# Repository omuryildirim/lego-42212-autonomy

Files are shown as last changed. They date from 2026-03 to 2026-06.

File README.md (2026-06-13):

# Autonomous electrified LEGO 42212

Electrify LEGO Technic set [#42212](https://www.lego.com/sv-se/product/ferrari-fxx-k-42212) with an ESP32-C3, a single drive motor, and a steering servo. Control it from a PC over BLE or USB. Roadmap: full self-driving autonomy.

Finished build
*Prototype: LEGO Technic 42212 with the drive motor, steering servo, and electronics mounted on the chassis.*

## What this is

- **Now**: a minimal, low-cost retrofit of LEGO #42212 with one drive motor, one steering servo, and wireless control from a PC.
- **Next**: onboard sensing and perception to make the car autonomous.
- **Constraint**: every part is chosen for price/performance. Stock hobby-grade modules, no exotic hardware.

Driving demo

*The drive motor turning the rear wheels through the gear train.*

SG90 steering in action

*The SG90 swinging the front wheels left and right through the adapter and linkage.*

## Prerequisites

- **VS Code** with the **PlatformIO IDE** extension, for building and flashing the firmware.
- **Python 3.9+**, for the desktop keyboard bridge.
- **A PC with Bluetooth Low Energy** (most laptops from the last ~5 years), only for BLE mode.
- **Git**, to clone this repo.
- The hardware listed in the [Bill of materials](#bill-of-materials) below, plus a USB-C cable to flash the ESP32-C3.

## Hardware

> [!NOTE]
> Recommended approach: build in three stages to keep the error rate down.
>
> 1. **Per-component bench tests on a breadboard.** Verify the servo, the N20 + DRV8833, and the buck each work in isolation on USB power. See [docs/](docs/) for the per-component guides.
> 2. **Full motherboard on the breadboard.** Wire all the modules together as they'll appear on the perfboard, run from battery power, and drive the car around. Catching a wrong wire here is a 5-second fix; on the perfboard it's a desoldering job.
> 3. **Transfer to the perfboard.** Only after the breadboard version works end-to-end.

Once each subsystem is bench-tested, the modules consolidate onto a single 40×60 mm perfboard "motherboard" that handles power, motor control, and BLE. Full layout, cell-by-cell wiring, and assembly notes are in [docs/perfboard-layout.md](docs/perfboard-layout.md).

### Bill of materials

| Component | Purpose | Approx. price (EUR) |
|---|---|---|
| ESP32-C3 SuperMini | MCU + BLE radio | €2–3 |
| GA12-N20 micro gear motor | Rear-axle drive | €1–2 |
| SG90 micro servo (or MG90, EMax ES08) | Steering | €1–2 |
| DRV8833 motor driver module | H-bridge for the N20 | €1–3 |
| MP1584EN buck converter | 5 V rail for ESP32 and servo | €1–2 |
| 5–26 V reverse-polarity protection board | Battery input safety | €1–2 |
| 4 A 30 V resettable polyfuse | Short-circuit protection | <€1 |
| 2× 18650 Li-ion cells + holder | Power source (~8.4 V fully charged) | €6–16 |
| 3× ceramic capacitors (~100 nF) (104) | Motor brush noise suppression | <€0.50 |
| 1× electrolytic  capacitors (~470 uF - min 16v) | Motor brush noise suppression | <€0.50 |
| 1× electrolytic  capacitors (~47-100 uF - min 25v) | Motor brush noise suppression | <€0.50 |

### Tools and consumables

| Item | Purpose |
|---|---|
| Breadboard | Bench-testing each subsystem before integration |
| Perfboard or small PCB | Final compact wiring |
| Soldering iron + solder | Headers, modules, motor leads |
| Heat-shrink tubing | Insulating splices |
| Zip ties + double-sided tape | Mechanical attachment to the LEGO chassis |
| Multimeter | Voltage and continuity checks before connecting the battery |

Prices are typical AliExpress and hobby-electronics ranges. In my experience you can get a better deals especially with AliExpress.

## Quick start

Once the hardware is bench-tested and the motherboard is assembled, getting the firmware and keyboard bridge running takes three steps:

1. Open this folder in VS Code with the PlatformIO extension. The PlatformIO target is `esp32-c3-devkitm-1`. This is the generic ESP32-C3 board ID and works for the SuperMini, DevKitM-1, and most other C3 boards. Change it in [platformio.ini](platformio.ini) only if you're on a non-standard variant.
2. Build and flash. Replace the port with whatever your OS assigns to the ESP32-C3 (Windows: `COM3`, macOS: `/dev/cu.usbmodem*`, Linux: `/dev/ttyACM0` or `/dev/ttyUSB0`).

   Windows (PowerShell):

   ```powershell
   & "$env:USERPROFILE\.platformio\penv\Scripts\platformio.exe" run -t upload --upload-port COM3
   ```

   macOS / Linux:

   ```bash
   ~/.platformio/penv/bin/platformio run -t upload --upload-port /dev/ttyACM0
   ```

   If `platformio` (or `pio`) is on your `PATH`, just run `pio run -t upload --upload-port <port>`.

3. Drive it. Two options that coexist; pick one (or enable both in [src/config.h](src/config.h)):

   **Wireless (BLE)**, enabled by default. Install Python deps, then run the keyboard bridge:

   ```bash
   pip install -r tools/requirements.txt
   python tools/keyboard_control.py --mode ble
   ```

   **USB serial**: set `ENABLE_SERIAL_INTERFACE 1` in [src/config.h](src/config.h), reflash, then:

   ```bash
   python tools/keyboard_control.py --mode serial --port <your-port>
   ```

   Controls: **W/A/S/D** or arrow keys, **Space** for emergency stop. Full BLE setup in [docs/ble-setup.md](docs/ble-setup.md).

## Design decisions

**ESP32-C3 over ESP32 / ESP32-S3.** Cheaper (~€3 vs. €5–8), single-core RISC-V is plenty for one motor and one servo, and built-in USB-serial saves an external UART chip. The tradeoff: the C3 supports BLE only (no Bluetooth Classic), so it cannot pair with PS or Xbox gamepads. It can still talk to any modern PC, phone, or BLE-native gamepad, which is enough for now.

**N20 + DRV8833 for drive.** N20 gear motors are the smallest credible drive option that fits inside a Technic chassis. The DRV8833 is the cheapest dual H-bridge that handles the N20's stall current (~1.5 A) without a heatsink. Two 100 nF capacitors across the motor terminals kill brush noise that would otherwise reset the ESP32.

**SG90 for steering.** A standard SG90 (or any MG90/ES08-class equivalent) is the lightest servo at this price point. Steering force on a LEGO chassis is tiny, so torque is not the limiter.

**MP1584EN buck for the 5 V rail.** Two 18650s in series sit at 6.4–8.4 V, too high for the SG90 and the ESP32, but fine for the motor through the DRV8833. The MP1584EN regulates the logic, motor driver and servo rail to a clean 5 V.

**Reverse-polarity board + polyfuse.** Lithium cells deliver enough current to destroy parts on a wiring mistake. The protection board guards against polarity flips during assembly; the 4 A polyfuse trips on a short. Combined cost is under €3, cheap insurance. Of course you can get protected 18650 batteries, e.g. XTAR, Nitecore etc., but that makes the batteries physically longer and naturally more expensive. So I prefered to buy unprotected batteries and implement an effortless basic protection myself.

## More documentation

Bench tests (run in this order before integrating on the chassis):

1. [Servo bench test](docs/servo-breadboard-setup.md): first SG90 check on USB-C power.
2. [N20 + DRV8833 bench test](docs/n20-breadboard-setup.md): first motor drive on USB-C power.
3. [Buck converter bench test](docs/buck-breadboard-setup.md): verify 5 V regulation before connecting 18650s.

Control software:

- [docs/ble-setup.md](docs/ble-setup.md): wireless setup, BLE UUIDs, command grammar.
- [tools/README.md](tools/README.md): desktop keyboard bridge.

Mechanical:

- [docs/3d-printing/README.md](docs/3d-printing/README.md): printable couplers for SG90, EMax ES08MA II, and GA12-N20 to LEGO Technic axles. I used [jlcpcb.com](https://jlcpcb.com) for printing, and I can only recommend them if you don't have access to 3D printers (or your local 3D printing alternatives are really expensive). Their shipping is pretty fast and they provide bunch of coupons for new customers. You can order couple of samples for every part this repository has under €3-5.

Motor placement
*Top view: the N20, SG90, buck, and ESP32-C3 mounted on the 42212 chassis.*

3D-printed adapters
*Printed N20 bracket and shaft coupler: the motor clips to a LEGO stud row and its D-shaft drives a LEGO axle.*

## Roadmap

- [x] Manual drive over USB serial
- [x] Manual drive over BLE
- [ ] ToF-based obstacle detection (ST VL53L8CX)
- [ ] Multi-sensor ToF array for wider coverage and local occupancy mapping
- [ ] Wheel odometry + IMU for pose estimation
- [ ] Graph-based SLAM with loop closure

## Project layout

```
src/
  main.cpp              motor + steering control loop
  config.h              feature flags, BLE UUIDs
  serial_interface.*    USB serial command parser
  ble_interface.*       BLE GATT server
tools/
  keyboard_control.py   desktop keyboard bridge (serial or BLE)
docs/                   wiring, bench tests, BLE setup, 3D prints
platformio.ini          PlatformIO env + libraries
```

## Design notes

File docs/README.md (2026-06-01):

# Documentation

These docs follow the recommended three-stage build (per-component bench → breadboard motherboard → perfboard), plus reference material for control software and mechanical bits. See the main [README](../README.md) for the high-level plan and bill of materials.

## Per-component bench tests

Each module verified on a breadboard from USB power, in order. Don't skip ahead.

1. [Servo bench test](servo-breadboard-setup.md): SG90 driven from a USB-powered ESP32-C3.
2. [N20 + DRV8833 bench test](n20-breadboard-setup.md): single motor through the H-bridge.
3. [Buck converter bench test](buck-breadboard-setup.md): MP1584EN verified before the 18650 pack goes anywhere near it.
4. **Full motherboard on a breadboard.** No separate doc; wire up the [perfboard layout](perfboard-layout.md) in jumper wires, mount the motors on the LEGO chassis, and test the steering and backwheel movmement from battery power. The most important sanity check before soldering: mechanical, hardware, and software all working end-to-end.

Editable diagrams: [servo-breadboard-setup.drawio](servo-breadboard-setup.drawio), [n20-breadboard-setup.drawio](n20-breadboard-setup.drawio).

## Perfboard motherboard

- [Perfboard layout](perfboard-layout.md): 40×60 mm board with cell-by-cell placement, color-coded wiring, and critical assembly notes. Build a breadboard version of this layout first (drive the car around from battery power) before committing anything to solder.

## Control

- [BLE control](ble-setup.md): interface flags, command grammar, BLE UUIDs, troubleshooting.
- [Desktop keyboard bridge](../tools/README.md): running `keyboard_control.py` in serial or BLE mode.

## Sensors

- [Sensor breadboard setup](sensor-breadboard-setup.md): wiring the MPU-9265 IMU and SATEL-VL53L8 ToF to the ESP32-C3.
- [Sensor mode & point cloud](sensor-mode-and-point-cloud.md): the `ENABLE_SENSOR_MODE` build, the snapshot stream format, and the `sensor_listen.py` / `pointcloud.py` tools (with IMU-fused, time-accumulated 3D point cloud).

## Mechanical

- [3D-printed adapters](3d-printing/README.md): couplers from SG90, EMax ES08MA II, and GA12-N20 shafts to LEGO Technic axles.
- [Motor mechanical integration](motor-integration.md): how the N20 drive motor and SG90 steering servo tie into the chassis, and the compliance sources at each stage.
- [Steering calibration](steering-calibration.md): `kServoSide` and `kSteeringTrim` tuning once the servo is on the chassis.

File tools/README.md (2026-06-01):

# Tools

This directory holds the desktop-side Python helpers:

- **`keyboard_control.py`** — drive the car from the keyboard (serial or BLE). Documented below.
- **`sensor_listen.py`** — print the sensor stream in sensor mode. See [Sensor mode & point cloud](../docs/sensor-mode-and-point-cloud.md).
- **`pointcloud.py`** — live IMU-fused 3D point cloud from the ToF sensor. See [Sensor mode & point cloud](../docs/sensor-mode-and-point-cloud.md).

# Running Keyboard Control Script

## Installation

From the project root, run:

```powershell
python --version
python -m venv .venv
.\.venv\Scripts\Activate.ps1
python -m pip install --upgrade pip
pip install -r tools/requirements.txt
```

## Usage

The keyboard_control.py script supports both **Serial (USB)** and **BLE (Wireless)** modes.

### Serial Mode (USB Connected)

First, find your ESP32-C3's COM port:

```powershell
# Method 1: Using serial tools
.\.venv\Scripts\python.exe -m serial.tools.list_ports -v

# Method 2: Using PlatformIO
& "$env:USERPROFILE\.platformio\penv\Scripts\platformio.exe" device list
```

If multiple ports are listed, run before and after connecting the board to identify which port is new.

Then start the keyboard bridge:

```powershell
python tools/keyboard_control.py --mode serial --port COM3
```

Replace `COM3` with your actual port number.

### BLE Mode (Wireless)

Make sure your ESP32-C3 has BLE enabled in [src/config.h](../src/config.h):

```cpp
#define ENABLE_BLE_INTERFACE 1
```

Then start the keyboard bridge in BLE mode:

```powershell
python tools/keyboard_control.py --mode ble
```

The script will automatically scan for and connect to "LEGO-42212".

## Default Keyboard Mapping

Once running, use these keys to control the car:

- **W** or **Up Arrow**: Forward
- **S** or **Down Arrow**: Reverse
- **A** or **Left Arrow**: Steer left
- **D** or **Right Arrow**: Steer right
- **Space**: Emergency stop / neutral
- **Close Window**: Exit

## Troubleshooting

### Serial mode: COM port not found

1. Check that ESP32-C3 is connected via USB-C
2. Try different ports if multiple are listed
3. Verify [src/config.h](../src/config.h) has `ENABLE_SERIAL_INTERFACE 1`

### Port appears/disappears repeatedly, or upload fails with `Failed to connect`

The running firmware is crashing and resetting the USB stack. Force the chip into ROM bootloader mode: **hold the BOOT button while plugging in USB**, then release. The port will stay stable and you can flash fresh firmware over the top. Press RESET (or replug) after flashing to run the new firmware.

### BLE mode: Device not found

1. Verify ESP32-C3 has `ENABLE_BLE_INTERFACE 1` in config
2. Power cycle the ESP32-C3 (disconnect/reconnect USB)
3. Check that bleak is installed: `pip install bleak`
4. Ensure your computer has Bluetooth enabled

### BLE imports error

If you get `ImportError: No module named 'bleak'`, install it:

```powershell
pip install bleak
```

## Firmware Notes

Before running either mode, ensure the firmware is compiled and flashed:

```powershell
& "$env:USERPROFILE\.platformio\penv\Scripts\platformio.exe" run -t upload --upload-port COM3
```

For dual-mode operation, you can enable both interfaces in [src/config.h](../src/config.h):

```cpp
#define ENABLE_SERIAL_INTERFACE 1
#define ENABLE_BLE_INTERFACE 1
```

This allows you to run the keyboard bridge in either mode and control the same car.

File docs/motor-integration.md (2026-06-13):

# Motor mechanical integration

How the two motors tie into the LEGO 42212 chassis: the GA12-N20 drive motor at the rear, and the SG90 steering servo at the front. Adapter and bracket part details live in [3d-printing/](3d-printing/README.md); this doc covers the surrounding integration and the mechanical compliance that affects control.

## Drive motor (N20)

The N20's rotation reaches the rear wheels through three stages, each adding some compliance worth being aware of when interpreting motor-side encoder data.

### Chain

1. **N20 D-shaft** drives the [3D-printed coupler](3d-printing/ga12-n20/README.md), which presents a LEGO Technic axle on its output side.
2. A **knob gear** on that axle meshes with a second knob gear on a perpendicular axle — the 90° change of direction.
3. The perpendicular axle carries a **small gear at each outer end**, each meshing with a **larger gear on a wheel shaft**. The size mismatch is a speed reduction: wheels turn slower than the perpendicular axle with proportionally more torque.

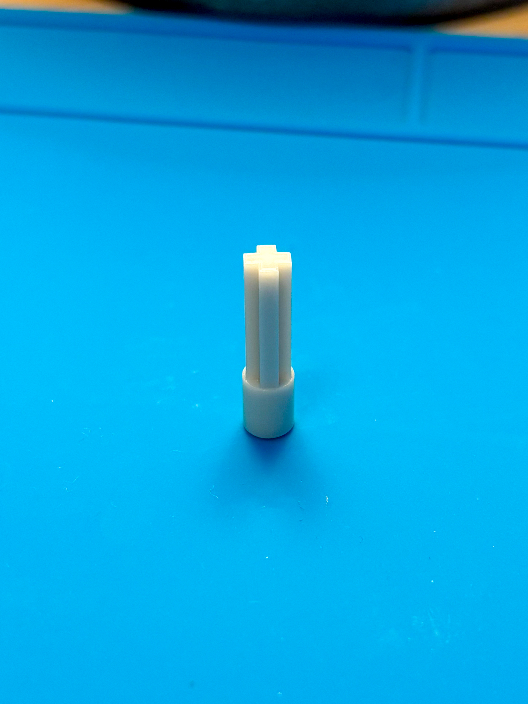
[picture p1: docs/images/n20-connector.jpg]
N20 shaft coupler

*Printed coupler: LEGO Technic axle profile on top, motor socket at the base.*

N20 coupler D-shaft socket
*The D-shaped bore that press-fits onto the N20's D-shaft.*

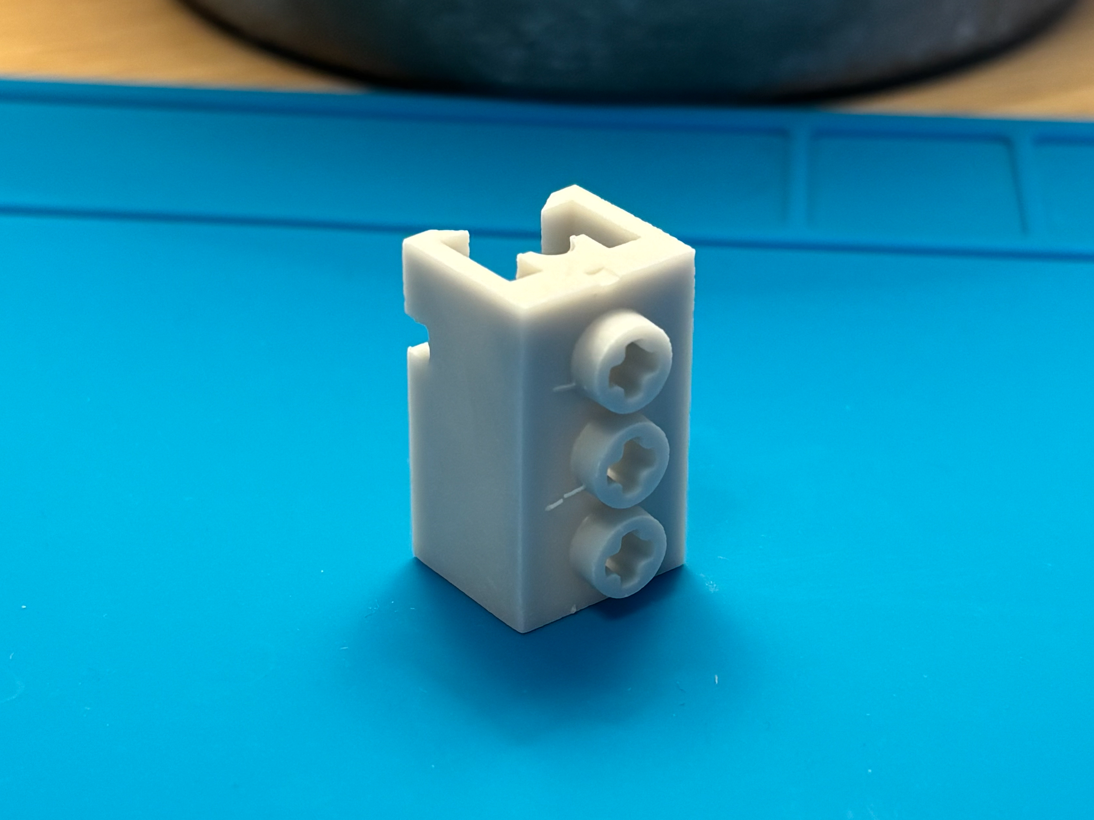
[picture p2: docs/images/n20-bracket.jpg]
N20 bracket

*Printed bracket: studs on top, Technic pin holes on the side, open motor cradle.*

N20 motor in the bracket with coupler attached
*Assembled: motor in the cradle, shaft coupler on the output, power leads exiting the open end.*

N20 bracket underside
*Underside view showing the motor seated in the cradle.*

N20 coupler driving the knob-gear train
*The N20 in its printed bracket: the coupler's LEGO axle drives the first knob gear, which meshes with a second on the perpendicular axle.*

N20 drive installed in the chassis
*Wider view of the rear drive: coupler → knob gears → perpendicular axle running across the chassis.*

N20 drive in action

*The N20 driving the rear wheels through the gear train.*

## Steering servo (SG90)

TBD — to document: servo mounting location in the chassis, the [3D-printed adapter](3d-printing/sg90/README.md) from servo horn to LEGO Technic axle, the linkage to the steering arm, and the asymmetry / compliance sources that motivate the firmware trim. The photos below show the current build.

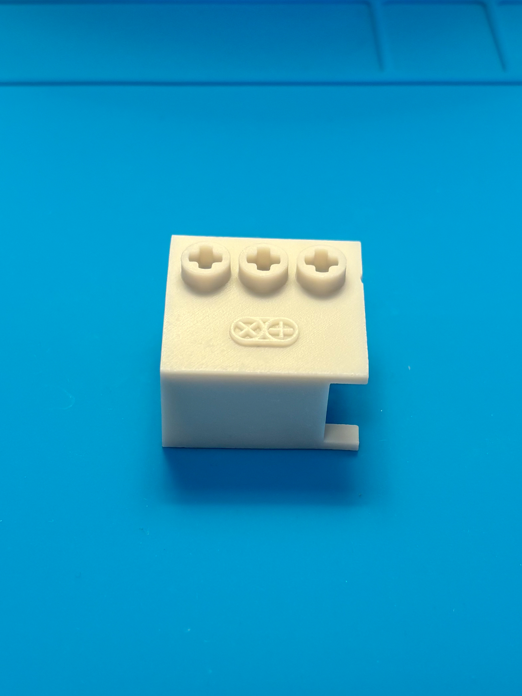
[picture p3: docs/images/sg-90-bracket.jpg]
SG90 in its printed LEGO bracket

*Printed mount that clips the SG90 to a LEGO stud row.*

SG90 mounted with the spline-to-axle adapter
*The servo in its bracket, with the spline-to-axle adapter on the output and the 3-pin lead exiting the side.*

Steering linkage in the chassis
*The adapter's LEGO axle drives the steering knob gear.*

Steering assembly installed
*Wider view of the front steering linkage on the chassis.*

SG90 steering in action

*The SG90 swinging the front wheels left and right through the adapter and linkage.*

Firmware-side calibration (`kServoSide`, `kSteeringTrim`) is documented in [steering-calibration.md](steering-calibration.md).

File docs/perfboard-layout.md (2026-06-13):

# Perfboard layout (40×60 mm motherboard)

Motherboard that integrates the ESP32-C3 SuperMini, MP1584EN buck, DRV8833, polyfuse, decoupling caps, and the SG90 servo connector on a single 40×60 mm perfboard. The reverse-polarity protection module mounts separately on the chassis (it has no solder pads).

Board: 20 columns × 14 rows (cols `1`–`20`, rows `A`–`N`), each hole isolated, with ~12 entrance pads along each short edge. Rows are printed bottom-to-top on the physical board, so **row A is at the bottom, row N is at the top**. The cell table below matches.

## Components

| Part | Footprint | Notes |
|---|---|---|
| ESP32-C3 SuperMini | cols 13–20, rows D & J (rotated 90° CCW) | Stackable male-female headers |
| MP1584EN buck | cols 1–8, rows B–G | Direct-solder using male-male pin headers |
| DRV8833 (12-pin, single VCC) | cols 1–7, rows I–N | Direct-solder using male-male pin headers. Single VCC pin powers motor *and* logic |
| SG90 3-pin connector | A11 (GND) / A12 (5V) / A13 (Sig) | Cable exits bottom edge |
| Polyfuse | A1 (PF1, load) / A3 (PF2, battery) | 3-cell lead span, body bridges A2 |
| 470 µF / 16 V electrolytic | C11 (−) / C12 (+) | SG90 bulk |
| 47 µF / 25 V electrolytic | K10 (+) / L10 (−) | DRV VCC bulk |
| 100 nF ceramic ×2 | K8 / L8 (DRV) and E11 / E12 (SG90) | No polarity |
| 100 nF ceramic | across N20 motor terminals | Off-board, soldered to the motor tabs themselves |

ESP32 mounts components-face up (antenna, USB-C, BOOT/RST visible). Its silkscreen labels are on the underside, so pinout diagrams in datasheets are mirrored relative to the cell-table positions once the board is flipped over to mount it.

## Cell table

```
            1     2     3     4     5     6     7     8     9    10    11    12    13    14    15    16    17    18    19    20
   N      SLP   ▒▒▒   ▒▒▒   ▒▒▒   ▒▒▒   ▒▒▒   IN4     ·     ·     ·     ·     ·     ·     ·     ·     ·     ·     ·     ·     ·
   M     OUT1   ▒▒▒   ▒▒▒   ▒▒▒   ▒▒▒   ▒▒▒   IN3     ·     ·     ·     ·     ·     ·     ·     ·     ·     ·     ·     ·     ·
   L     OUT2   ▒▒▒   ▒▒▒   ▒▒▒   ▒▒▒   ▒▒▒   GND  104-     ·   47-     ·     ·     ·     ·     ·     ·     ·     ·     ·     ·
   K     OUT3   ▒▒▒   ▒▒▒   ▒▒▒   ▒▒▒   ▒▒▒   VCC  104+     ·   47+     ·     ·     ·     ·     ·     ·     ·     ·     ·     ·
   J     OUT4   ▒▒▒   ▒▒▒   ▒▒▒   ▒▒▒   ▒▒▒   IN2     ·     ·     ·     ·     ·   e5V    eG   e3V    e4    e3    e2    e1    e0
   I      FAU   ▒▒▒   ▒▒▒   ▒▒▒   ▒▒▒   ▒▒▒   IN1     ·     ·     ·     ·     ·   ▓▓▓   ▓▓▓   ▓▓▓   ▓▓▓   ▓▓▓   ▓▓▓   ▓▓▓   ▓▓▓
   H        ·     ·     ·     ·     ·     ·     ·     ·     ·     ·     ·     ·   ▓▓▓   ▓▓▓   ▓▓▓   ▓▓▓   ▓▓▓   ▓▓▓   ▓▓▓   ▓▓▓
   G      vi-   ░░░   ░░░   ░░░   ░░░   ░░░   ░░░   vo-     ·     ·     ·     ·   ▓▓▓   ▓▓▓   ▓▓▓   ▓▓▓   ▓▓▓   ▓▓▓   ▓▓▓   ▓▓▓
   F      vi-   ░░░   ░░░   ░░░   ░░░   ░░░   ░░░  vo-★     ·     ·     ·     ·   ▓▓▓   ▓▓▓   ▓▓▓   ▓▓▓   ▓▓▓   ▓▓▓   ▓▓▓   ▓▓▓
   E        ·   ░░░   ░░░   ░░░   ░░░   ░░░   ░░░     ·     ·     ·   104   104   ▓▓▓   ▓▓▓   ▓▓▓   ▓▓▓   ▓▓▓   ▓▓▓   ▓▓▓   ▓▓▓
   D        ·   ░░░   ░░░   ░░░   ░░░   ░░░   ░░░     ·     ·     ·     ·     ·    e5    e6    e7    e8    e9   e10   e20   e21
   C      vi+   ░░░   ░░░   ░░░   ░░░   ░░░   ░░░   vo+     ·     ·  470-  470+     ·     ·     ·     ·     ·     ·     ·     ·
   B      vi+   ░░░   ░░░   ░░░   ░░░   ░░░   ░░░   vo+     ·     ·     ·     ·     ·     ·     ·     ·     ·     ·     ·     ·
   A      PF1     ·   PF2     ·     ·     ·     ·     ·     ·     ·   GND    5V   Sig     ·     ·     ·     ·     ·     ·     ·

   BAT+ enters at the row-A left entrance pad, BAT− at the row-B left entrance pad.
   N20 motor wires solder directly to M1 (OUT1) and L1 (OUT2), twisted pair exits LEFT edge.
```

**Key.** `▓` `░` `▒` are cells under a module's PCB body (unreachable, leave unused). `★` at F8 marks the star ground node — the buck GND net (F8/G8 paired vo− pads, electrically tied to F1/G1 vi− through the buck module). `e5V`/`eG`/`e3V`/`e0`…`e21` are ESP32 pin labels (`e` prefix). DRV `VCC` is the combined motor+logic supply. Cap labels carry polarity in the `+`/`−` suffix; `104` (ceramic) is non-polar. Buck-DRV gap row (row H cols 1–7) and buck-cap gap cols (cols 9–10) are intentionally empty for module-body clearance.

## Wiring

All jumpers go on the **back (solder) side** of the perfboard, hence modules sit on top with pin headers sticking down. The buck's paired pins (`vi+`×2, `vi-`×2, `vo+`×2, `vo-`×2) are the same net; jumper one to the other for extra current handling.

### Wire color key

One color per net so the back of the board stays traceable later. Substitute whatever's in your kit if you're missing a color.

| Color | Net | Gauge |
|---|---|---|
| **Red** | 5 V rail (buck Vo+ to all loads), `nSLEEP` tie | 22 AWG |
| **Yellow** | Battery rail (BAT+ → polyfuse → buck `vi+`) | 22 AWG |
| **Black** | GND, returns to star ★ at F8/G8 (buck vo−), including BAT− | 22 AWG |
| **Orange** | Servo PWM signal | 28–30 AWG |
| **Green** | DRV `IN1` | 28–30 AWG |
| **Blue** | DRV `IN2` | 28–30 AWG |

### Connections

Check off each wire as you solder it. One checkbox per physical wire run — a single wire can serve multiple adjacent pins on the same net (e.g. K7+K8+K10 chained along row K, or A12+C12+E12 chained down column 12).

#### 5 V rail (red, 22 AWG)

- [ ] C8 (buck vo+, paired with B8) → J13 (ESP32 5V)
- [ ] C8 → K7 (DRV VCC), K8 (104 cap +), K10 (47 cap +) — chained along row K
- [ ] C8 → A12 (SG90 5V), C12 (470 cap +), E12 (104 cap) — chained down column 12

#### nSLEEP tie (red)

- [ ] K7 (DRV VCC) → N1 (DRV nSLEEP)

#### Battery rail (yellow, 22 AWG)

- [ ] Row-A entrance pad → A3 (PF2), routed on the back side since A2 sits under the polyfuse body
- [ ] A1 (PF1) → B1 / C1 (buck vi+, paired)

#### GND star at F8/G8 (black, 22 AWG)

Star is the buck GND net — F8/G8 (paired vo− pads), electrically tied to F1/G1 (vi−) through the buck module. Two local clusters chain their returns; each cluster joins ★ with one wire (see Critical assembly notes).

**Load cluster** (lands directly on ★):

- [ ] A11 (SG90 GND) → C11 (470 cap −) → E11 (104 cap) → F8 — chained up column 11
- [ ] F8 ↔ G8 (paired buck vo− pads)
- [ ] G8 → J14 (ESP32 GND)
- [ ] Row-B entrance pad → F1 (buck vi−)

**DRV cluster** (bridged to ★ with one dedicated wire):

- [ ] L7 (DRV GND) → L8 (104 cap −) → L10 (47 cap −) — chained along row L
- [ ] L8 (or any pad on the L-row chain) → F8 — single bridge wire; must land directly on ★, not chain through the ESP32 or SG90 returns

#### Signal lines (28–30 AWG)

- [ ] D13 (`e5` = GPIO5) → A13 (Sig), 3-cell jumper through empty B13 / C13 — servo PWM, orange
- [ ] J17 (`e3` = GPIO3) → I7 (IN1) — motor IN1, green
- [ ] J16 (`e4` = GPIO4) → J7 (IN2) — motor IN2, blue

#### Motor leads (off-board, any color)

- [ ] M1 (OUT1), L1 (OUT2) → N20 terminals (twisted pair, exits left edge)

ESP32 strap pins to avoid driving at boot: GPIO2, GPIO8, GPIO9 (BOOT button). GPIO20/21 are default UART0, usable as GPIO if you don't need `Serial.print` over USB-CDC.

## Assembly technique

- **Tin stranded wire ends before pushing them into the board.** Strip ~5 mm, twist the strands tight, then heat the wire and feed solder to it (not to the iron) until it wicks into a solid pin. The end pushes through a hole cleanly without fraying. Solid-core 22 AWG hookup wire is easier still; reserve stranded for connections that move (motor leads, battery to perfboard).
- **Always route wires through a perfboard hole**, never solder them straight to a pin in the air. The hole anchors the wire mechanically; without it, the cable can flex and short an adjacent pin (the ESP32's GND and 5 V pads sit right next to each other).
- **Clean flux residue if you want a clean look or want to inspect joints later.** With no-clean flux (e.g. ChipQuik SMD4300-10M) the residue is inert and technically doesn't need removal. With rosin flux it's worth cleaning — the creamy yellow film absorbs moisture over time and obscures joints. Either way, clean dark black patches regardless: they mean the iron dwelled too long, and burnt flux can become slightly conductive. Method: isopropyl alcohol (90 %+) and an old toothbrush, with cotton swabs for the tight gaps between pins. Avoid water-based cleaners — moisture wicks under header sockets and stays there.

## Critical assembly notes

1. **Star ground at F8/G8 (buck vo−).** Local clusters chain their returns and bridge to ★ with one dedicated wire each. The rule isn't "every wire to ★" — it's that the motor return current (~1.5 A peak) must not share a wire with the ESP32's GND or the buck's feedback reference, or it will modulate BLE. Keep the DRV cluster's bridge wire isolated.
2. **Antenna clearance.** The ESP32 chip antenna overhangs past col 20 at roughly rows F–G. Keep ≥2 cm of clearance from metal axles, screws, and motor cases. Plastic LEGO is RF-transparent and fine.
3. **Polyfuse direction.** PF2 (A3) is the battery side, PF1 (A1) is the load side. Route the BAT+ wire on the back of the board. Don't run it through A2 on the top.
4. **Cap polarity.** Stripe / short lead = negative. 470 µF: stripe to C11. 47 µF: stripe to L10. Reverse polarity = pop.
5. **Twisted motor pair.** Wires from M1 / L1 to the N20 are twisted ~1 turn/cm. The 100 nF cap across the N20 terminals on the motor body itself kills most of the brush noise. It's the single most important cap in the build.
6. **nSLEEP tie.** The DRV8833 stays asleep unless `nSLEEP` is HIGH. Short jumper from N1 to K7 (VCC) at assembly. If you ever want software sleep control, route to a spare GPIO instead.
7. **Buck pin pitch.** MP1584EN pin spacing isn't exactly 0.1". Bend each pin slightly outward at the perfboard surface before pushing the module down and don't force it.
8. **USB-C accessibility.** The connector overhangs the col-13 edge. That edge must be reachable from outside the chassis shell, otherwise you're lifting the perfboard out for every reflash.

## Power chain

```
2× 18650 (8.4 V fully charged) → reverse-polarity board → row-A entrance pad
                                                    │
                                                    ▼ back-side wire across row A
                                              A3 (PF2) ── polyfuse ── A1 (PF1)
                                                                          │
                                                                          ▼ 1-row jumper
                                                                    B1/C1 (vi+)
                                                                    MP1584EN buck
                                                                          │
                                                                          ▼ vo+ at B8/C8
                                                                      5 V rail
                                                                          │
                                                              ┌───────────┼──────────────┐
                                                              ▼           ▼              ▼
                                                       J13 (ESP32)  A12 (SG90)    K7 (DRV VCC)
                                                                                          │
                                                                                          ▼ OUT1/OUT2 at M1/L1
                                                                                       N20 motor
```

## N20 motor decoupling (off-board)

The most important cap in the entire build is the one at the motor: brushed DC motors radiate HF noise from arc-induced brush currents that escape down the wires before any board-level cap can shunt them. **Solder a 100 nF ceramic directly across the two N20 terminal tabs, on the motor body itself.**

*Optional*: the "every dB matters" RC/drone trick is to add two more 100 nF caps from each terminal to the motor case (scuff and tin a spot on the can, solder the cap leads). Skip it unless you actually see noise; the across-terminals cap alone is enough for normal use.

## Mounted on the chassis

Motherboard mounted on the chassis
*The ESP32-C3 SuperMini and the rest of the motherboard mounted on the 42212 chassis, wiring routed to the motor and servo.*

Motherboard side view
*Side view: the perfboard sits above the chassis with the battery lead (XT connector) and module wiring exiting cleanly.*

## SG90 servo notes

The 470 µF + 100 nF stack on the perfboard sits a couple rows above the SG90 connector, decoupling the servo as close to its connector as you can get without opening the case. If you ever see jitter at stall or rapid step changes: open the SG90 (4 small Phillips screws) and add a 10–22 µF ceramic across V+ / GND on its internal PCB, or add another small ceramic at the connector for higher-frequency content.

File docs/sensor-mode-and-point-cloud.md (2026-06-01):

# Sensor mode & point cloud

The firmware has a second build-time personality: instead of driving the car it
can stream the **MPU-9265 IMU** and **VL53L8CX 8×8 Time-of-Flight** sensor over
USB serial and BLE. Two host-side tools consume that stream — a plain text
listener and a live 3D point-cloud visualizer that fuses the IMU to accumulate
geometry over time.

For wiring the two sensors to the ESP32-C3, see
[sensor-breadboard-setup.md](sensor-breadboard-setup.md). This doc covers the
firmware mode and the software side.

## Enabling sensor mode

The mode is selected by a flag in [src/config.h](../src/config.h):

```cpp
// 0 = car control (default), 1 = sensor bench
#define ENABLE_SENSOR_MODE 0
```

- `0` (default): car control — the motor + steering servo respond to drive
  commands. See [ble-setup.md](ble-setup.md).
- `1`: sensor bench — stream IMU + ToF snapshots; the motor outputs are held
  inert.

Set it to `1`, then build and flash:

```powershell
& "$env:USERPROFILE\.platformio\penv\Scripts\platformio.exe" run -t upload --upload-port COM4
```

The two modes live in separate translation units guarded by the flag
([car_control.cpp](../src/car_control.cpp), [sensor_bench.cpp](../src/sensor_bench.cpp))
behind a shared `Mode::setup()`/`Mode::loop()` interface ([mode.h](../src/mode.h)),
so only the selected mode is compiled in. Both serial and BLE are available in
either mode.

## Snapshot stream format

In sensor mode the firmware emits one snapshot every 100 ms (10 Hz) to **both**
USB serial and the BLE TX characteristic. The payload is identical on both
transports:

```
==================== Sensors @ 11046ms ====================
IMU  ax=+0.054 ay=+0.046 az=+1.034 g
     gx=  +3.54 gy=  -1.10 gz=  -0.87 dps   T=31.3C
ToF (mm, 8x8):
      1729  1737  1747  1752  1751  1773  1749  1750
      1728  1736  1746  1750  1758  1772  1763  1771
      1745  1740  1753  1764  1768  1763  1771  1786
      1745  1735  1756  1774  1771  1774  1763  1769
      1721  1690  1710  1764  1762  1779  1752  1766
      1714  1692  1708  1748  1772  1765  1770  1757
      1721  1729  1713  1752  1750  1751  1740  1741
      1712  1715  1737  1727  1741  1753  1752  1704
============================================================
```

- **Timestamp** — milliseconds since boot.
- **IMU** — accel in g (±2 g range), gyro in deg/s (±250 dps), die temperature.
- **ToF** — 8×8 grid of per-zone distances in mm (`0` / very large = no target or
  out of range).

When the ToF fails to initialize, the grid is replaced by a self-diagnosing
line, e.g. `ToF  offline (failed at init_sensor, status=255, 0x29 NACK)` — see
the troubleshooting section of [sensor-breadboard-setup.md](sensor-breadboard-setup.md).

The rate (10 Hz) is chosen to match the ToF's 8×8 ranging cap and to keep a
full ~680-byte snapshot within the 115200-baud serial budget while giving the
host enough IMU samples for gyro integration.

## Reading the stream — `sensor_listen.py`

Prints snapshots as they arrive. Useful for a quick sanity check.

```powershell
# Serial (USB) — close any other program holding the port first
python tools/sensor_listen.py --mode serial --port COM4

# BLE (wireless)
python tools/sensor_listen.py --mode ble
```

Flags: `--mode {serial,ble}`, `--port COMx` (serial), `--baud` (default 115200).

## Point cloud — `pointcloud.py`

Turns the stream into a live 3D point cloud, with IMU-based orientation tracking
and accumulation over time.

```powershell
python tools/pointcloud.py --mode serial --port COM4
```

### What it does

1. **Projection.** Each of the 64 ToF zones looks out along a slightly different
   angle within the sensor's ~45°×45° field of view (5.625° per zone in 8×8).
   Each distance is projected through its zone angle into a 3D point
   (`x`=right, `y`=up, `z`=forward).
2. **Orientation.** A complementary filter fuses the IMU: the accelerometer
   anchors absolute roll/pitch from gravity, and the gyro tracks fast motion and
   integrates yaw. Live roll/pitch/yaw is shown on screen.
3. **Accumulation.** Each frame is rotated into a gravity-aligned world frame and
   merged into a voxel grid, so panning/tilting the sensor builds up a denser
   cloud than any single 8×8 frame (current frame in orange; accumulated points
   colored faintly by height).

### Controls

| Key | Action |
|---|---|
| `r` | Reset the accumulated cloud and orientation |
| `a` | Toggle accumulation on/off |
| `space` | Pause/resume |

### Flags

| Flag | Default | Purpose |
|---|---|---|
| `--mode {serial,ble}` | `serial` | Transport |
| `--port COMx` | — | Serial port (serial mode) |
| `--baud` | `115200` | Serial baud |
| `--max-range` | `2000` | Initial plot half-extent (mm) |
| `--voxel-mm` | `40` | Accumulation voxel size (mm) |
| `--alpha` | `0.95` | Complementary-filter gyro weight (0..1) |
| `--mount-deg` | `0,0,0` | Fixed ToF→IMU mounting rotation `rx,ry,rz` (deg) |

### Limitations & calibration

These are inherent to the available sensors, not bugs:

- **Rotation-only.** There is no position tracking (accelerometer
  double-integration drifts uselessly), so this is a *pan/tilt-in-place*
  scanner, not SLAM. Accumulation assumes the sensor rotates about a roughly
  fixed point.
- **Yaw drifts.** With no magnetometer, integrated yaw slowly wanders. Press `r`
  to re-zero when it does.
- **Mounting alignment.** Fusion assumes the ToF and IMU are **rigidly mounted
  with aligned axes** (x=right, y=up, z=forward). With the ToF on flying leads
  and the IMU on the perfboard, accumulation is only meaningful once the two are
  fixed together. If the cloud tilts the wrong way under motion, correct the
  fixed offset with `--mount-deg`.

### Serial vs. BLE for the point cloud

A full 8×8 snapshot (~680 B) far exceeds the default BLE notify payload (~20 B),
so a connected BLE central receives only fragments unless MTU is negotiated.
**Use serial for the point cloud.** BLE works well for `sensor_listen.py`
spot-checks and for the smaller car-control command traffic.

## Installation

All tools share one requirements file:

```powershell
python -m venv .venv
.\.venv\Scripts\Activate.ps1
pip install -r tools/requirements.txt
```

This pulls `pyserial` and `bleak` (transports) plus `numpy` and `matplotlib`
(point-cloud math and rendering).

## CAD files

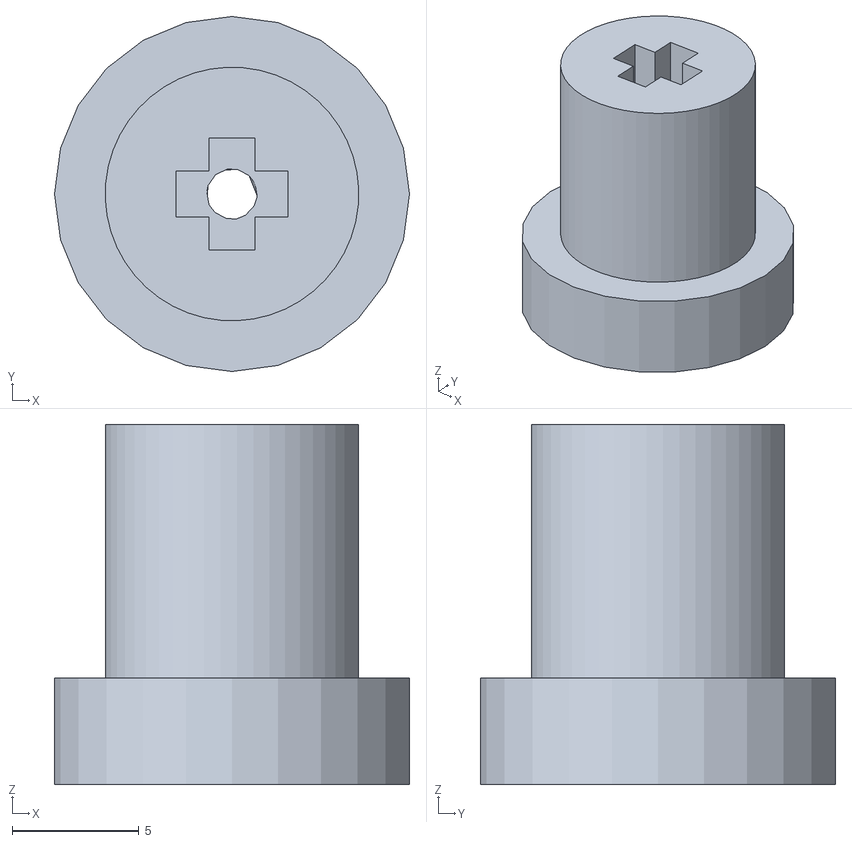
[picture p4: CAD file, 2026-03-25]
docs/3d-printing/emax-es08ma-ii/EMax (SG90) - v2 - 4.4mm - 3.9mm.stl
14.0 x 14.0 x 14.2

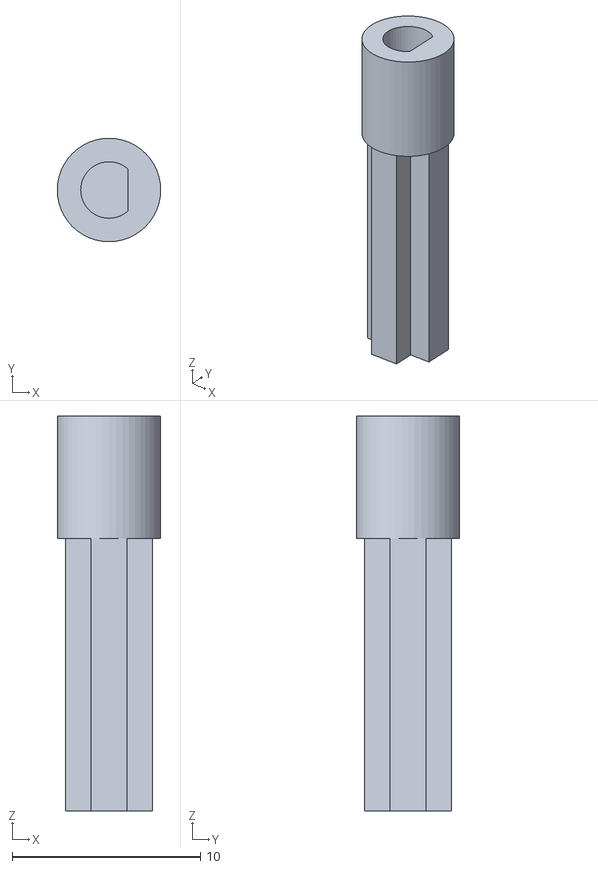
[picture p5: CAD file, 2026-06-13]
docs/3d-printing/ga12-n20/N20 - 2.5mm d hole - 2l.stl
5.50 x 5.50 x 21.0

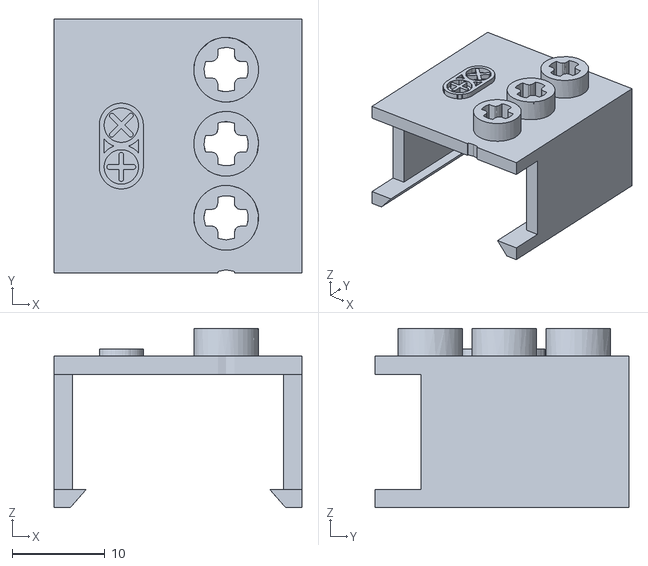
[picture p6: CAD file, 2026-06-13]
docs/3d-printing/sg90/SG90-bracket.stl
26.8 x 27.5 x 19.4

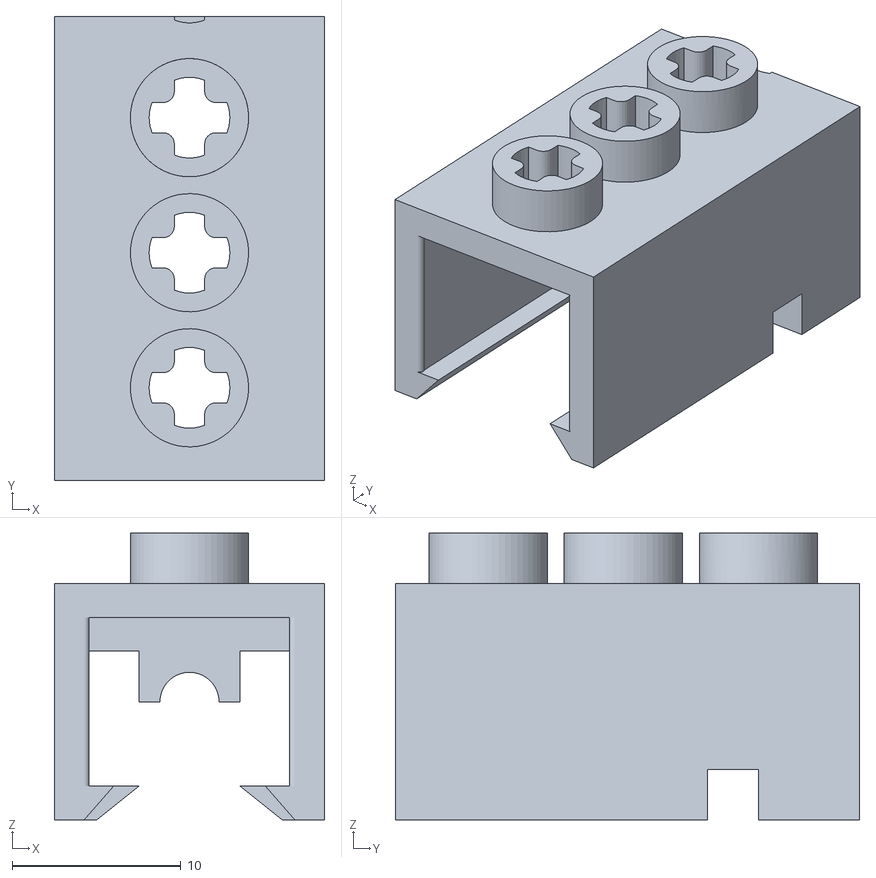
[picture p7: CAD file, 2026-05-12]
docs/3d-printing/ga12-n20/N20 - Bracket.stl
16.0 x 27.5 x 17.0

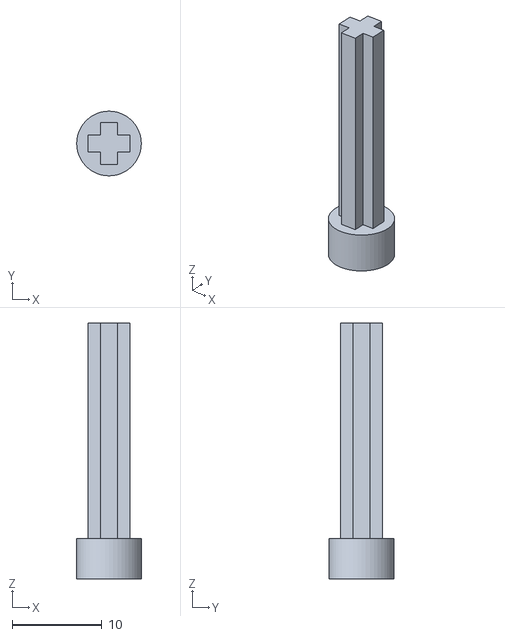
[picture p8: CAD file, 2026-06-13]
docs/3d-printing/sg90/S90 - 4.8mm - 6.5mm - 3l axle.stl
7.20 x 7.20 x 28.5

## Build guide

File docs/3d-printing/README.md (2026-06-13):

# 3D Printing

Printable connector parts for integrating common hobby servos and small motors with Lego Technic axle pieces.

## Available adapters

- [EMax ES08MA II mini servo to Lego axle adapter](./emax-es08ma-ii/README.md)
- [SG90 mini servo to Lego axle adapter and bracket module](./sg90/README.md)
- [GA12-N20 micro metal gear motor to Lego axle adapter and bracket module](./ga12-n20/README.md)

## Notes

- These parts are intended to couple a motor or servo output shaft to Lego Technic axle-compatible pieces.
- The Lego axle side is designed around pieces such as Lego Technic, Axle 6L (#3706), with nominal 4.4 mm x 4.4 mm dimensions.

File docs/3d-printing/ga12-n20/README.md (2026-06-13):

# GA12-N20 motor adapters

Two printable parts for fitting a GA12-N20 micro metal gear motor into a LEGO Technic chassis: a shaft coupler that converts the motor's D-shaft into a standard LEGO axle, and a bracket that clamps the motor body to a stud row.

## Shaft coupler (`N20 - 2.5mm d hole - 2l.stl`)

Press-fits onto the motor's D-shaft on one end and accepts a LEGO Technic axle on the other, so the motor can drive an axle-driven gear train directly.

### Interface details

- Motor side: GA12-N20 D-shaft, 3.0 mm nominal diameter, flat narrowed to ~2.5 mm
- Lego side: axle-compatible interface for pieces such as Lego Technic, Axle 6L (#3706)
- Lego axle nominal dimensions: 4.4 mm x 4.4 mm

### Part dimensions

- Overall length: 16 mm
- Engagement length per side: 8 mm

N20 shaft coupler
*The printed coupler: LEGO Technic axle profile on top, motor socket at the base.*

N20 coupler D-shaft socket
*The D-shaped bore that press-fits onto the GA12-N20's D-shaft.*

## Motor body bracket (`N20 - Bracket.stl`)

LEGO-stud-compatible block with an internal cradle that holds the GA12-N20's cylindrical body. The output shaft pokes out one end (where the shaft coupler attaches), and the opposite side is open so the motor's power leads exit cleanly. The top has standard LEGO studs, so the whole bracket clips onto any baseplate, Technic frame, or beam with a matching stud row.

### Interface details

- Motor side: cradle sized to the GA12-N20's 12 mm body diameter
- Lego side: standard LEGO stud spacing on the top face for chassis mounting

N20 bracket
*The bracket alone: studs on top, Technic pin holes on the side, open motor cradle.*

N20 motor in the bracket with coupler attached
*Assembled: motor in the cradle, shaft coupler on the output, power leads exiting the open end.*

N20 bracket underside
*Underside view showing the motor seated in the cradle.*

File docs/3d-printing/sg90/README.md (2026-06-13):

# SG90 mini servo adapters

Two printable parts for fitting an SG90 mini servo into a LEGO Technic chassis: a spline adapter that converts the servo's output spline into a standard LEGO axle, and a bracket that clips the servo body onto a stud row.

## Spline adapter (`S90 - 4.8mm - 6.5mm - 3l axle.stl`)

Connects an SG90 mini servo to LEGO pieces.

### Interface details

- Servo side: SG90, 21T spline connection
- Servo spline nominal diameter: 4.8 mm
- Lego side: axle-compatible interface for pieces such as Lego Technic, Axle 6L (#3706)
- Lego axle nominal dimensions: 4.4 mm x 4.4 mm

SG90 axle adapter
*The printed adapter: LEGO Technic axle profile on top, servo-spline socket at the base.*

SG90 adapter spline socket
*The 21T spline socket that presses onto the SG90 output shaft.*

### Design note

This adapter was inspired by testing Lego Technic, Pin Connector Round 2L with Slot (#62462) as a press-fit option on an SG90 spline. The printed part was created to provide a more stable axle connector.

## Servo bracket (`SG90-bracket.stl`)

LEGO-stud-compatible block that holds the SG90's body. The output spline pokes out one end (where the spline adapter attaches), and the side is open so the 3-pin servo lead exits cleanly. The top has standard LEGO studs, so the bracket clips onto any baseplate, Technic frame, or beam with a matching stud row.

### Interface details

- Servo side: cradle sized to the SG90 body
- Lego side: standard LEGO stud spacing on the top face for chassis mounting

SG90 bracket
*The bracket alone: studs on top, Technic pin holes on the side, open servo cradle.*

SG90 in the bracket with the spline adapter attached
*Assembled: servo in the cradle, spline adapter on the output, 3-pin lead exiting the side.*

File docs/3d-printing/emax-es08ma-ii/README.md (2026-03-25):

# EMax ES08MA II Mini Servo To Lego Axle Adapter

EMax ES08MA II is a full metal version of the commonly used SG90-size mini servo.

This piece is designed to connect an EMax ES08MA II mini servo to Lego pieces.

## Interface details

- Servo side: EMax ES08MA II, Phi 3.9 15T spline connection
- Servo spline nominal diameter: 3.9 mm
- Lego side: axle-compatible interface for pieces such as Lego Technic, Axle 6L (#3706)
- Lego axle nominal dimensions: 4.4 mm x 4.4 mm

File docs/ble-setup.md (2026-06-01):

# BLE control

The firmware exposes a Nordic-UART-style BLE service so any BLE-capable device (PC, phone, BLE gamepad) can drive the car wirelessly. The Python keyboard bridge in [tools/keyboard_control.py](../tools/keyboard_control.py) is the easiest client.

## Enable / disable interfaces

Both interfaces live behind flags in [src/config.h](../src/config.h):

```cpp
#define ENABLE_SERIAL_INTERFACE 1   // USB serial commands
#define ENABLE_BLE_INTERFACE    1   // BLE wireless commands
```

Set either or both to `1`. They coexist cleanly — running with both lets you swap between cabled debug and wireless drive without reflashing.

Car control is the default build. To stream sensors instead of driving, set `ENABLE_SENSOR_MODE 1` — see [Sensor mode & point cloud](sensor-mode-and-point-cloud.md).

## BLE profile

The ESP32-C3 advertises as `LEGO-42212` and runs as a GATT peripheral with a Nordic-UART-compatible service:

| | Value |
|---|---|
| Device name | `LEGO-42212` |
| Service UUID | `6e400001-b5a3-f393-e0a9-e50e24dcca9e` |
| RX characteristic (write) | `6e400002-b5a3-f393-e0a9-e50e24dcca9e` |
| TX characteristic (notify) | `6e400003-b5a3-f393-e0a9-e50e24dcca9e` |

Clients write ASCII commands to the RX characteristic.

## Command grammar

Same for BLE and serial. Newline-terminated, ASCII:

```
drive <throttle -1..1> <steering -1..1>
throttle <value -1..1>
steering <value -1..1>
stop
help
```

Examples: `drive 0.5 0.0`, `drive 0.7 -0.3`, `stop`.

A 500 ms watchdog stops the car if no command arrives — applies to both transports.

## Drive it from your PC

```bash
pip install -r tools/requirements.txt
python tools/keyboard_control.py --mode ble
```

The script scans for `LEGO-42212` and connects automatically. Controls: **W/A/S/D** or arrow keys, **Space** = emergency stop.

## Drive it from a generic BLE client

Any GATT client works — useful for debugging:

- **nRF Connect for Desktop** ([download](https://www.nordicsemi.com/Products/Development-tools/nRF-Connect-for-Desktop)) — connect to `LEGO-42212`, write ASCII bytes to the RX characteristic.
- **LightBlue** or **Bluefruit Connect** on iOS / Android — same idea from a phone.

## Latency

Roughly 20–100 ms per BLE write vs. 1–10 ms for USB serial. Both are well within the 500 ms watchdog and feel fine for manual driving.

## Troubleshooting

**Device doesn't show up in scans** — confirm `ENABLE_BLE_INTERFACE 1`, reflash, then power-cycle the ESP32. Sanity-check with nRF Connect; if it sees `LEGO-42212` the firmware is fine and the issue is on the client side.

**Script can't connect** — on Windows, allow BLE under Settings → Privacy → Bluetooth. Move closer to the ESP32. Check the script's "available devices" list (printed when no match is found).

**Connection drops** — typical at 10–30 m range or behind walls. The ESP32 re-advertises automatically; reconnect.

**Commands seem to do nothing** — verify it works over USB serial first to rule out hardware. Then re-check pins, the polyfuse, and battery state.

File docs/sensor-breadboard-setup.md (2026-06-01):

# Sensors bench test (VL53L8 ToF + MPU-9265 IMU)

Read both sensors over I2C and stream a snapshot table over USB serial and BLE every 500 ms. No motor drive in this mode — the DRV8833 inputs are held low so the buck rail can stay connected without anything moving.

## You need

- ESP32-C3 SuperMini (loose on a breadboard, or the assembled perfboard with the 18650 pack disconnected)
- USB-C cable to the laptop
- MPU-9265 breakout (any MPU-9250-pin-compatible board works)
- SATEL-VL53L8 satellite breakout
- Breadboard and jumper wires
- Two ~4.7 kΩ I2C pull-ups to 3V3 (most MPU breakouts already have them; check before adding more)

## Pins and wires

Both sensors share one I2C bus. SDA and SCL each fan out from a single ESP32 pin to **both** sensor breakouts in parallel — easiest on a breadboard is to drop a short jumper from the ESP32 pin to a free rail column, then run one wire from that column to each sensor. Default 7-bit addresses don't collide: MPU-9265 at `0x68`, VL53L8 at `0x29`.

### Wire-by-wire

One row per physical wire. 13 wires total: 5 to the MPU, 8 to the SATEL.

| # | From (ESP32-C3) | To | Net |
|---|---|---|---|
| 1 | 3V3 | MPU `VCC` | 3.3 V |
| 2 | GND | MPU `GND` | GND |
| 3 | GPIO 6 | MPU `SDA` | I2C SDA |
| 4 | GPIO 7 | MPU `SCL` | I2C SCL |
| 5 | GND | MPU `AD0` | sets address `0x68` (skip if breakout ties AD0 low on board) |
| 6 | **5V / VBUS** | SATEL `5VO` | **5 V** — board power input (see note below) |
| 7 | GND | SATEL `GND` | GND |
| 8 | GPIO 6 | SATEL `SDA` (`MOSI_SDA`) | I2C SDA (same net as wire 3) |
| 9 | GPIO 7 | SATEL `SCL` (`MCLK_SCL`) | I2C SCL (same net as wire 4) |
| 10 | GPIO 10 | SATEL `LPn` | ToF enable |
| 11 | 3V3 | SATEL `PWREN` | enables the onboard regulators (logic enable, not a supply) |
| 12 | GND | SATEL `SPI_I2C_N` | selects I2C mode (must be low) |
| 13 | 3V3 | SATEL `NCS` | tie high for I2C mode |

Wires 3 and 8 are the same I2C-SDA net; wires 4 and 9 are the same I2C-SCL net. Tie them at a breadboard column rather than running two long wires from the ESP32.

> **Power the SATEL from 5 V, not 3.3 V.** The SATEL-VL53L8 carries its own LDOs that generate the sensor's three internal rails (AVDD 3.3 V, IOVDD, CORE 1.8 V) from a single **5 V input on `5VO`**, gated by `PWREN`. The header pins labelled `1V8`, `3V3`, and `IOVDD` are regulator **outputs / test points — leave them unconnected.** Do *not* feed 3.3 V into them (that back-feeds an LDO output) and do *not* expect 3.3 V on `PWREN` alone to power the board — `PWREN` is only an enable. With no 5 V on `5VO`, the chip never powers up and NACKs at `0x29`. The ESP32-C3 SuperMini exposes 5 V on its `5V`/`VBUS` pad while USB is connected.

### What lands where on the perfboard

GPIO 6 / 7 break out at perfboard pads `D14` / `D15`, GPIO 10 at `D18`, 3V3 at `J15`, GND at `J14`. The MPU sits on the perfboard at row N (pads N10–N20); the SATEL stays off-board on the breadboard with flying leads back to those same pads.

### Pins you can ignore on the SATEL

`I2C_RST` and `INT` can be left floating for this test — the firmware uses polled reads. Everything else above is required: `5VO` (power), `PWREN`, `SPI_I2C_N`, and `NCS` must all be wired or the chip won't appear on the bus.

## Procedure

1. Wire as above. Check 3V3, 5V, and GND with a multimeter before plugging either sensor in.
2. Build and flash. PlatformIO will pull `stm32duino/STM32duino VL53L8CX` on first build — the ~80 KB firmware blob lives in flash and takes a couple seconds to upload to the sensor on every boot.
3. Open the USB serial monitor at 115200 baud, **or** connect a BLE central to `LEGO-42212` and subscribe to the TX characteristic. Same payload goes to both.

## Expected

Boot log:

```
LEGO 42212 sensor bench
MPU WHO_AM_I=0x71
MPU ready: yes
ToF ready: yes
Streaming sensor snapshots
```

Then every 500 ms:

```
==================== Sensors @ 12345ms ====================
IMU  ax=+0.012 ay=-0.034 az=+0.998 g
     gx=  -0.21 gy=  +0.45 gz=  -0.18 dps   T=24.3C
ToF (mm, 4x4):
       123   145   167   189
       211   233   255   277
       299   321   343   365
       387   409   431   453
============================================================
```

Sanity checks:

- Lay the IMU flat: `az ≈ +1.000`, `ax`/`ay ≈ 0`. Flip it: `az ≈ -1.000`.
- Wave a hand 10 cm above the ToF: matching zones drop to ~100 mm; uncovered zones stay at the ceiling distance.
- Rotate the board around one axis: `gx`/`gy`/`gz` reads the corresponding rate, near zero when still.

## If it misbehaves

The `ToF offline` line in the stream carries its own diagnosis: the step that failed, the status code, and a live probe of the sensor's I2C address, e.g. `ToF  offline (failed at init_sensor, status=255, 0x29 NACK)`.

- **`MPU: WHO_AM_I read failed`** — pull-ups missing, SDA/SCL swapped, or 3V3 not present at the MPU.
- **`MPU WHO_AM_I=0xFF`** — open bus. Push the jumpers back in.
- **`ToF  offline ... 0x29 NACK`** — the sensor isn't on the bus at all. Almost always power or mode-select on the SATEL: no 5 V on `5VO` (the most common mistake — `PWREN` tied to 3V3 only *enables* the regulators, it doesn't power them), `SPI_I2C_N` not pulled low (board stuck in SPI mode), `NCS` not tied high, or `LPn`/GPIO 10 not actually reaching the board. The MPU answering on the same SDA/SCL proves the bus itself is fine, so isolate to the SATEL.
- **`ToF  offline ... 0x29 ACK` but `failed at init_sensor`** — chip is powered and addressable but the firmware-blob upload failed. Usually the I2C clock is too fast for your flying-lead wiring; `kI2cClockHz` is already dropped to `100000` in [src/main.cpp](../src/main.cpp). Shorten the leads or power-cycle.
- **`ToF  no new frame` forever** — `start_ranging` succeeded but no frame ever lands. Power-cycle (the firmware blob upload occasionally hangs the chip after a partial init).
- **All ToF cells read `0` or `65535`** — sensor looking at no target / out of range. Place a hand at ~20 cm.
- **ESP32-C3 resets at boot** — the VL53L8 inrush can dip the rail on USB power if your laptop's port is weak. Try a different port or add a 10 µF ceramic across the SATEL board's 5V/GND pins.

## Where things go on the perfboard

The MPU sits on the perfboard at the row-N strip above the DRV8833 (pads N10–N20). Three wires reach it from the ESP32 pads:

- `J15` (3V3) → MPU VCC
- `J14` (GND) → MPU GND
- `D14` (GPIO 6) → MPU SDA, `D15` (GPIO 7) → MPU SCL

The VL53L8 stays off-board for now and connects through breadboard jumpers: the shared `D14`/`D15` (GPIO 6/7) SDA/SCL and `J14` (GND), plus `D18` (GPIO 10) for LPn. Note its supply is **5 V on `5VO`**, not the 3V3 `J15` net the MPU uses — source 5 V from the ESP32 `5V`/`VBUS` pad (confirm which perfboard pad carries VBUS before wiring). It also needs `PWREN`→3V3, `SPI_I2C_N`→GND, and `NCS`→3V3 as described above.

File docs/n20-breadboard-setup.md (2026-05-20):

# N20 + DRV8833 bench test

Second bench test: spin the N20 motor through the DRV8833, still on USB power. Done after the [servo test](servo-breadboard-setup.md).

## You need

- ESP32-C3 board + USB-C cable
- Breadboard and jumper wires
- DRV8833 breakout
- One GA12-N20 motor

Leave the 18650 pack and the MP1584EN out for this step. The servo can be left disconnected for a clean motor-only test.

## Pins and wires

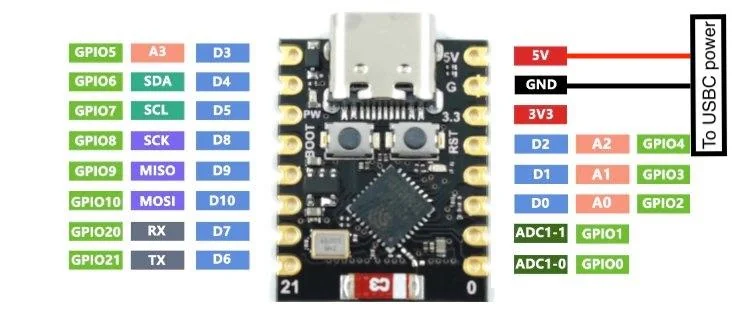
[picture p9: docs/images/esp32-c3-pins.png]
ESP32-C3 pinout


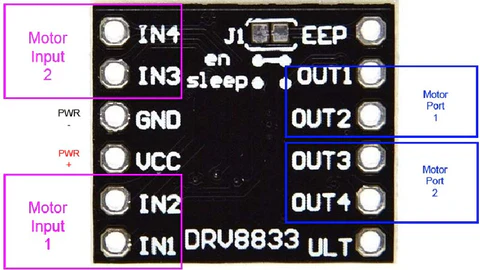
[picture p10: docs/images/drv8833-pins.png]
DRV8833 pinout


The firmware uses one half of the DRV8833 (channel A):

| ESP32-C3 | DRV8833 |
|---|---|
| GPIO 3 | IN1 (or AIN1) |
| GPIO 4 | IN2 (or AIN2) |
| 5V / VBUS | VM |
| GND | GND |

Motor leads go to **OUT1** and **OUT2** (or AOUT1/AOUT2). If the motor spins the wrong way, swap them.

If your DRV8833 breakout exposes `nSLEEP` / `SLP`, tie it high. Most breakouts do this on the board already.

## Procedure

1. Wire as above. Confirm grounds are shared and the motor leads are on OUT1/OUT2 only.
2. Plug the ESP32-C3 into your laptop and flash the firmware.
3. Start the keyboard bridge ([../README.md](../README.md#quick-start)).
4. Tap **W** and **S** briefly. Keep the motor unloaded and don't hold the key down.

## Expected

- **W** spins one direction, **S** the other, key release stops the motor.

## If it misbehaves

- **Motor doesn't spin** — check VM has 5 V, grounds shared, IN1/IN2 on GPIO 3/4, motor on OUT1/OUT2, and the keyboard bridge is actually sending commands.
- **ESP32-C3 resets** — USB can't supply the inrush. Disconnect the servo, keep the motor unloaded, use short bursts. The proper fix is the buck + battery setup later.

## Why USB power is fine here, but not for driving

USB delivers ~500 mA. That's enough for unloaded short bursts but nowhere near the N20's stall current (~1.5 A). Once the car is mechanically loaded you must move motor power to the 18650 pack via the [buck stage](buck-breadboard-setup.md).

For an editable wiring diagram: [n20-breadboard-setup.drawio](n20-breadboard-setup.drawio).

Next: [buck converter bench test](buck-breadboard-setup.md).

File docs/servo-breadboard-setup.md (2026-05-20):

# Servo bench test

First and simplest test: drive the SG90 from a USB-powered ESP32-C3, no motor driver, no battery.

## You need

- ESP32-C3 board + USB-C cable
- Breadboard and jumper wires
- SG90 servo (or MG90 / EMax ES08 equivalent)

Leave everything else (DRV8833, N20 motor, buck, batteries) out of this step.

## Pins and wires

> [!WARNING]  
> Please be very careful on power pin connections to servo. If you accidentally wire GND and 5V pins in reverse, your poor SG90 will burn itself down in couple of seconds.

ESP32-C3 pinout

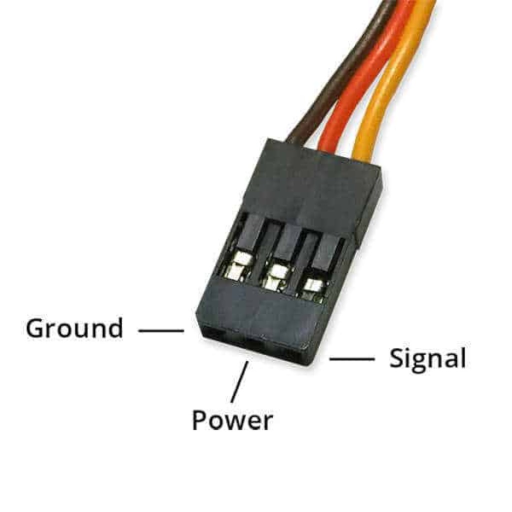
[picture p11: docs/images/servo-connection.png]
SG90 wiring


| Servo wire | Goes to |
|---|---|
| Orange / yellow (signal) | ESP32-C3 **GPIO 5** |
| Red (+5 V) | ESP32-C3 **5V / VBUS** |
| Brown / black (GND) | ESP32-C3 **GND** |

Run the servo's red wire to **5 V**, never to 3V3 and never directly to a GPIO.

## Procedure

1. Wire the servo as above.
2. Plug the ESP32-C3 into your laptop. Flash the firmware.
3. Start the keyboard bridge ([../README.md](../README.md#quick-start)).
4. Press **A** and **D** to steer left/right. Don't press W/S — no drive motor is wired yet.

## Expected

- Servo centers at startup.
- **A** / **D** move it to each side; releasing returns it toward center.

## If it misbehaves

- **Servo doesn't move** — check 5 V on the red wire, common ground with the ESP32, signal on GPIO 5, and that the keyboard bridge actually connected.
- **ESP32-C3 resets when the servo moves** — USB can't supply the current spike. Detach the horn so the servo is unloaded for this test, or move the servo to a separate 5 V supply later (keep grounds shared).

For an editable wiring diagram: [servo-breadboard-setup.drawio](servo-breadboard-setup.drawio).

Once this is stable, continue to the [N20 + DRV8833 bench test](n20-breadboard-setup.md). After the servo is connected to the steering linkage on the chassis, see [steering calibration](steering-calibration.md) to tune `kServoSide` and `kSteeringTrim`.

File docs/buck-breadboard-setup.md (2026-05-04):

# Buck converter bench test

Third bench test: confirm the MP1584EN regulates a stepped-down output before you ever connect the 18650 pack.

## You need

- ESP32-C3 board + USB-C cable
- Breadboard and jumper wires
- MP1584EN buck converter module
- Multimeter

Do **not** connect the 18650 pack, the servo, or the DRV8833 yet.

## Goal

Power the buck from the ESP32-C3's 5 V rail (USB power), measure the output, and dial the trimpot to a known voltage. This proves the module works and teaches you the trimming feel before any battery is involved.

## Wiring

| From | To |
|---|---|
| ESP32-C3 5V / VBUS | Buck **IN+** |
| ESP32-C3 GND | Buck **IN-** |
| Multimeter (V) | Buck **OUT+** to **OUT-** |

If the module has duplicate pads on each terminal, those are the same node — use whichever is convenient.

## Important: a buck only steps down

With ~5 V at the input, the output **must** be lower than ~5 V (the regulator needs headroom). For this USB-powered test, target one of:

- **3.3 V** — confirms it regulates down cleanly.
- **4.0 V** — confirms it still regulates near the top of its range.

Don't try to dial 5 V here — you'd be running the regulator out of headroom.

## Procedure

1. Wire IN+ / IN- only. Leave OUT+ / OUT- going only to the multimeter.
2. Plug in the ESP32-C3 (USB power).
3. Read the output. Adjust the trimpot **slowly** with a small screwdriver until you hit your target.

> [!NOTE]
> The MP1584EN can read unstable on the multimeter at no load — values can drift. Putting a 220 Ω–330 Ω resistor across OUT+ / OUT- gives the regulator something to push against and the reading settles. Real loads (DRV8833, servo) do the same thing.

## Don't

- Don't tie the buck output back into the ESP32-C3's 5 V pin while the board is also USB-powered. You'd be fighting two sources on the same rail.
- Don't connect both the 18650 pack and USB to the same rail simultaneously.
- Don't trim the buck without a multimeter on the output.

## Once it regulates cleanly

That's it for this bench step. The next stage is wiring the buck on the battery side, in this order:

```
18650 pack → reverse-polarity board → polyfuse → buck IN → buck OUT (5 V) → ESP32-C3, servo, DRV8833 logic
                                                          ↘ raw battery → DRV8833 VM (motor power)
```

Set the output back to **5.0 V** once you're powering it from the 2S 18650 pack (8.4 V down to 6.4 V), and re-measure under load before connecting anything sensitive.

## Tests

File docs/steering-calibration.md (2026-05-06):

# Steering calibration

Once the [servo bench test](servo-breadboard-setup.md) works and the servo is connected to the steering linkage on the chassis, two constants in [../src/main.cpp](../src/main.cpp) align the firmware with your physical build. Edit, reflash, and retest after each change.

## `kServoSide`

Servo mount orientation. Set to `+1` when the servo's label faces up, `-1` when it faces down. The `-1` case mirrors left/right inside the firmware so steering matches the driver's perspective.

**Symptom:** pressing **A** turns the wheels right (and **D** turns them left). Flip the sign.

## `kSteeringTrim`

Fractional bias added to every steering input, scaled by the maximum steering angle. Range roughly `-1.0..1.0`. Compensates for asymmetry in the linkage so the wheels rest straight when the controller is at center.

**Symptom:** the wheels sit off-center when no key is pressed. Nudge `kSteeringTrim` in small steps, e.g. `0.05`, until they track straight. Positive values bias one way, negative the other — direction depends on linkage geometry, so try a small step and observe.

The trim is applied in the same space as the user input, so flipping `kServoSide` also flips the effective direction of the trim. After changing `kServoSide`, re-check the trim.

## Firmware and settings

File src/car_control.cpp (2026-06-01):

#include "config.h"

#if !ENABLE_SENSOR_MODE

// Car control mode: drive the N20 motor + steering servo from serial/BLE
// commands. This is the default build (ENABLE_SENSOR_MODE == 0).

#include <Arduino.h>
#include <ESP32Servo.h>
#include "mode.h"

namespace {

constexpr int kMotorIn1Pin = 3;
constexpr int kMotorIn2Pin = 4;
constexpr int kServoPin = 5;

constexpr int kMotorPwmChannelA = 0;
constexpr int kMotorPwmChannelB = 1;
constexpr int kMotorPwmFrequencyHz = 20000;
constexpr int kMotorPwmResolutionBits = 8;
constexpr int kMotorPwmMaxDuty = (1 << kMotorPwmResolutionBits) - 1;

constexpr int kServoMinPulseUs = 500;
constexpr int kServoMaxPulseUs = 2400;
constexpr int kSteeringCenterDeg = 90;
constexpr int kSteeringMaxOffsetDeg = 35;
// Mechanical trim added to every steering input so the linkage rests centered.
constexpr float kSteeringTrim = 0.2f;
// Servo mount orientation: +1 if the label faces up, -1 if it faces down. The
// -1 case mirrors steering left/right to match the driver's perspective.
constexpr int kServoSide = -1;

constexpr float kThrottleDeadzone = 0.10f;
constexpr float kSteeringDeadzone = 0.08f;
constexpr uint32_t kCommandTimeoutMs = 500;

Servo steeringServo;
float currentThrottle = 0.0f;
float currentSteering = 0.0f;
uint32_t lastCommandMs = 0;

float clampUnit(float value) {
  if (value > 1.0f) {
    return 1.0f;
  }
  if (value < -1.0f) {
    return -1.0f;
  }
  return value;
}

float applyDeadzone(float value, float deadzone) {
  if (fabsf(value) < deadzone) {
    return 0.0f;
  }

  const float magnitude = (fabsf(value) - deadzone) / (1.0f - deadzone);
  return copysignf(magnitude, value);
}

void setMotorThrottle(float throttle) {
  const float clipped = applyDeadzone(clampUnit(throttle), kThrottleDeadzone);
  const int duty = static_cast<int>(fabsf(clipped) * kMotorPwmMaxDuty);

  if (duty == 0) {
    ledcDetachPin(kMotorIn1Pin);
    ledcDetachPin(kMotorIn2Pin);
    pinMode(kMotorIn1Pin, OUTPUT);
    pinMode(kMotorIn2Pin, OUTPUT);
    digitalWrite(kMotorIn1Pin, HIGH);
    digitalWrite(kMotorIn2Pin, HIGH);
    return;
  }

  if (duty >= kMotorPwmMaxDuty) {
    ledcDetachPin(kMotorIn1Pin);
    ledcDetachPin(kMotorIn2Pin);
    pinMode(kMotorIn1Pin, OUTPUT);
    pinMode(kMotorIn2Pin, OUTPUT);
    digitalWrite(kMotorIn1Pin, clipped > 0.0f ? HIGH : LOW);
    digitalWrite(kMotorIn2Pin, clipped > 0.0f ? LOW : HIGH);
    return;
  }

  if (clipped > 0.0f) {
    ledcAttachPin(kMotorIn1Pin, kMotorPwmChannelA);
    ledcDetachPin(kMotorIn2Pin);
    pinMode(kMotorIn2Pin, OUTPUT);
    ledcWrite(kMotorPwmChannelA, duty);
    digitalWrite(kMotorIn2Pin, LOW);
    return;
  }

  if (clipped < 0.0f) {
    ledcDetachPin(kMotorIn1Pin);
    pinMode(kMotorIn1Pin, OUTPUT);
    digitalWrite(kMotorIn1Pin, LOW);
    ledcAttachPin(kMotorIn2Pin, kMotorPwmChannelB);
    ledcWrite(kMotorPwmChannelB, duty);
    return;
  }

  ledcDetachPin(kMotorIn1Pin);
  ledcDetachPin(kMotorIn2Pin);
  pinMode(kMotorIn1Pin, OUTPUT);
  pinMode(kMotorIn2Pin, OUTPUT);
  digitalWrite(kMotorIn1Pin, HIGH);
  digitalWrite(kMotorIn2Pin, HIGH);
}

void setSteering(float steering) {
  const float clipped = applyDeadzone(clampUnit(steering), kSteeringDeadzone);
  const int targetAngle = kSteeringCenterDeg + static_cast<int>(kServoSide * (clipped + kSteeringTrim) * kSteeringMaxOffsetDeg);
  steeringServo.write(targetAngle);
}

void applyOutputs(float throttle, float steering) {
  currentThrottle = clampUnit(throttle);
  currentSteering = clampUnit(steering);
  setMotorThrottle(currentThrottle);
  setSteering(currentSteering);
}

void setNeutralOutputs() {
  applyOutputs(0.0f, 0.0f);
}

void printStatus(const char* source) {
  Serial.printf("%s throttle=%.2f steering=%.2f\n", source, currentThrottle, currentSteering);
}

void markCommandReceived() {
  lastCommandMs = millis();
}

}  // namespace

namespace Mode {

void setup() {
  Serial.println("Starting LEGO 42212 controller");

  ledcSetup(kMotorPwmChannelA, kMotorPwmFrequencyHz, kMotorPwmResolutionBits);
  ledcSetup(kMotorPwmChannelB, kMotorPwmFrequencyHz, kMotorPwmResolutionBits);
  ledcAttachPin(kMotorIn1Pin, kMotorPwmChannelA);
  ledcAttachPin(kMotorIn2Pin, kMotorPwmChannelB);

  steeringServo.setPeriodHertz(50);
  steeringServo.attach(kServoPin, kServoMinPulseUs, kServoMaxPulseUs);
  setNeutralOutputs();
}

void loop() {
  if (lastCommandMs != 0 && millis() - lastCommandMs > kCommandTimeoutMs) {
    setNeutralOutputs();
    lastCommandMs = 0;
    printStatus("timeout");
  }
  delay(20);
}

}  // namespace Mode

void printHelp() {
  Serial.println("Commands:");
  Serial.println("  drive <throttle -1..1> <steering -1..1>");
  Serial.println("  throttle <value -1..1>");
  Serial.println("  steering <value -1..1>");
  Serial.println("  stop");
  Serial.println("  help");
}

void processCommand(char* line) {
  float firstValue = 0.0f;
  float secondValue = 0.0f;

  if (sscanf(line, "drive %f %f", &firstValue, &secondValue) == 2) {
    applyOutputs(firstValue, secondValue);
    markCommandReceived();
    printStatus("drive");
    return;
  }

  if (sscanf(line, "throttle %f", &firstValue) == 1) {
    applyOutputs(firstValue, currentSteering);
    markCommandReceived();
    printStatus("throttle");
    return;
  }

  if (sscanf(line, "steering %f", &firstValue) == 1) {
    applyOutputs(currentThrottle, firstValue);
    markCommandReceived();
    printStatus("steering");
    return;
  }

  if (strcmp(line, "stop") == 0) {
    setNeutralOutputs();
    markCommandReceived();
    printStatus("stop");
    return;
  }

  if (strcmp(line, "help") == 0) {
    printHelp();
    return;
  }

  Serial.printf("Unknown command: %s\n", line);
  printHelp();
}

#endif  // !ENABLE_SENSOR_MODE

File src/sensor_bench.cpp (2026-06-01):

#include "config.h"

#if ENABLE_SENSOR_MODE

// Sensor bench mode: read the MPU-9265 IMU and VL53L8CX ToF over a shared I2C
// bus and stream snapshots over USB serial and BLE. The motor outputs are held
// inert. Active when ENABLE_SENSOR_MODE == 1.

#include <Arduino.h>
#include <Wire.h>
#include <vl53l8cx_class.h>
#include "mode.h"
#include "ble_interface.h"

namespace {

// Motor pins from the perfboard. Held inert in sensor bench mode so the DRV8833
// outputs stay high-impedance even if the buck is powered.
constexpr int kMotorIn1Pin = 3;
constexpr int kMotorIn2Pin = 4;

// I2C shared by MPU-9265 (on perfboard, row N) and SATEL-VL53L8 (off-board).
constexpr int kI2cSdaPin = 6;
constexpr int kI2cSclPin = 7;
// 100 kHz, not 400 kHz: the ToF's ~80 KB firmware-blob upload in init_sensor()
// is marginal at 400 kHz over the SATEL's flying-lead wiring. The IMU's tiny
// single-register reads tolerate 400 kHz, but the bulk upload does not.
constexpr uint32_t kI2cClockHz = 100000;

// VL53L8CX low-power enable. HIGH = chip awake and on the I2C bus.
constexpr int kTofLpnPin = 10;

constexpr uint8_t kMpuI2cAddr = 0x68;
constexpr uint8_t kMpuRegPwrMgmt1 = 0x6B;
constexpr uint8_t kMpuRegWhoAmI = 0x75;
constexpr uint8_t kMpuRegAccelXoutH = 0x3B;

// Default ranges after wake: ±2 g, ±250 dps. See MPU-9250 register map §4.5.
constexpr float kAccelLsbPerG = 16384.0f;
constexpr float kGyroLsbPerDps = 131.0f;

// 10 Hz: matches the ToF 10 Hz ranging and gives the host enough IMU samples
// for usable gyro integration / orientation tracking. A full 8x8 snapshot is
// ~680 B, so 10 Hz (~6.8 KB/s) fits comfortably in 115200 baud (~11.5 KB/s).
constexpr uint32_t kSensorPeriodMs = 100;

// ToF grid edge: 8 -> 8x8 (64 zones). Max ranging frequency is 15 Hz at 8x8.
constexpr int kTofGrid = 8;

VL53L8CX tof(&Wire, kTofLpnPin);
bool mpuReady = false;
bool tofReady = false;
// Captured by setupTof() so the failure is visible in the snapshot stream even
// when the boot log was missed (native USB-CDC can't be reset via RTS).
const char* tofFailStep = "none";
uint8_t tofFailStatus = 0;
uint32_t lastSensorTickMs = 0;
// Large enough for the 8x8 grid (64 zones ~430 chars) plus IMU + framing.
char snapshotBuf[1024];

bool mpuReadRegs(uint8_t reg, uint8_t* buf, size_t len) {
  Wire.beginTransmission(kMpuI2cAddr);
  Wire.write(reg);
  if (Wire.endTransmission(false) != 0) {
    return false;
  }
  const size_t received = Wire.requestFrom(static_cast<uint8_t>(kMpuI2cAddr), static_cast<uint8_t>(len));
  if (received != len) {
    return false;
  }
  for (size_t i = 0; i < len; ++i) {
    buf[i] = Wire.read();
  }
  return true;
}

bool mpuWriteReg(uint8_t reg, uint8_t value) {
  Wire.beginTransmission(kMpuI2cAddr);
  Wire.write(reg);
  Wire.write(value);
  return Wire.endTransmission() == 0;
}

bool setupMpu() {
  uint8_t whoami = 0;
  if (!mpuReadRegs(kMpuRegWhoAmI, &whoami, 1)) {
    Serial.println("MPU: WHO_AM_I read failed");
    return false;
  }
  Serial.printf("MPU WHO_AM_I=0x%02X\n", whoami);
  if (whoami == 0x00 || whoami == 0xFF) {
    return false;
  }
  if (!mpuWriteReg(kMpuRegPwrMgmt1, 0x00)) {
    Serial.println("MPU: wake failed");
    return false;
  }
  delay(50);
  return true;
}

bool setupTof() {
  pinMode(kTofLpnPin, OUTPUT);
  digitalWrite(kTofLpnPin, HIGH);
  delay(10);

  uint8_t status = tof.begin();
  if (status != 0) {
    tofFailStep = "begin";
    tofFailStatus = status;
    Serial.printf("ToF: begin() failed (status=%u)\n", status);
    return false;
  }
  // init_sensor() uploads the ~80 KB firmware blob; takes a few seconds.
  status = tof.init_sensor();
  if (status != 0) {
    tofFailStep = "init_sensor";
    tofFailStatus = status;
    Serial.printf("ToF: init_sensor() failed (status=%u)\n", status);
    return false;
  }
  status = tof.vl53l8cx_set_resolution(VL53L8CX_RESOLUTION_8X8);
  if (status != 0) {
    tofFailStep = "set_resolution";
    tofFailStatus = status;
    Serial.printf("ToF: set_resolution failed (status=%u)\n", status);
    return false;
  }
  status = tof.vl53l8cx_set_ranging_frequency_hz(10);
  if (status != 0) {
    tofFailStep = "set_freq";
    tofFailStatus = status;
    Serial.printf("ToF: set_ranging_frequency_hz failed (status=%u)\n", status);
    return false;
  }
  status = tof.vl53l8cx_start_ranging();
  if (status != 0) {
    tofFailStep = "start_ranging";
    tofFailStatus = status;
    Serial.printf("ToF: start_ranging failed (status=%u)\n", status);
    return false;
  }
  return true;
}

void initMotorPinsInert() {
  pinMode(kMotorIn1Pin, OUTPUT);
  pinMode(kMotorIn2Pin, OUTPUT);
  digitalWrite(kMotorIn1Pin, LOW);
  digitalWrite(kMotorIn2Pin, LOW);
}

size_t appendImuSection(char* buf, size_t cap) {
  if (!mpuReady) {
    return snprintf(buf, cap, "IMU  offline\n");
  }

  uint8_t raw[14] = {0};
  if (!mpuReadRegs(kMpuRegAccelXoutH, raw, sizeof(raw))) {
    return snprintf(buf, cap, "IMU  read failed\n");
  }

  const int16_t ax = static_cast<int16_t>((raw[0] << 8) | raw[1]);
  const int16_t ay = static_cast<int16_t>((raw[2] << 8) | raw[3]);
  const int16_t az = static_cast<int16_t>((raw[4] << 8) | raw[5]);
  const int16_t tempRaw = static_cast<int16_t>((raw[6] << 8) | raw[7]);
  const int16_t gx = static_cast<int16_t>((raw[8] << 8) | raw[9]);
  const int16_t gy = static_cast<int16_t>((raw[10] << 8) | raw[11]);
  const int16_t gz = static_cast<int16_t>((raw[12] << 8) | raw[13]);
  const float tempC = tempRaw / 333.87f + 21.0f;

  return snprintf(buf, cap,
                  "IMU  ax=%+6.3f ay=%+6.3f az=%+6.3f g\n"
                  "     gx=%+7.2f gy=%+7.2f gz=%+7.2f dps   T=%.1fC\n",
                  ax / kAccelLsbPerG, ay / kAccelLsbPerG, az / kAccelLsbPerG,
                  gx / kGyroLsbPerDps, gy / kGyroLsbPerDps, gz / kGyroLsbPerDps,
                  tempC);
}
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

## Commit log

2026-03-10 feat: implement n20 and servo controller using serial input
2026-03-20 feat: add first board setup step
2026-03-20 fix: keyboard serial connection is not stable
    [keyboard_control.py]
2026-03-20 feat: step two guide for n20 motor installation
2026-03-20 fix: esp32 should send low and high outputs to motor driver
    [main.cpp]
2026-03-25 feat: sg90 lego connector 3d parts
    [SG90 - 4.4mm - 4.8mm.stl, SG90 - v2 - 4.4mm - 4.8mm.stl]
2026-03-25 feat: n20 lego connector 3d parts
    [N20 - 4.4mm.stl]
2026-03-25 feat: emax-es08ma-ii lego connector 3d parts
    [EMax (SG90) - v2 - 4.4mm - 3.9mm.stl]
2026-03-25 chore: 3d printing introduction docs
2026-04-04 chore: add buck breadboard docs
2026-05-04 fix: add a starting offset angle due to physical position of the motor
    [main.cpp]
2026-05-04 chore: add pin images and simplify hardware setup docs
2026-05-06 feat: add servo side calibration
2026-05-10 chore: perfboard assembly guidelines
2026-05-11 chore: three stage build guidelines
2026-05-13 chore: motor integration documentation (wip)
2026-05-14 chore: assembly technique
2026-05-20 fix: update pins according to perfboard assignment
    [main.cpp]
2026-05-21 chore: gnd management and better wiring guideline
2026-06-01 feat: scaffold MPU + VL53L8CX I2C sensor bench
    Add the sensor-bench firmware that reads the MPU-9265 IMU and the
    VL53L8CX ToF over a shared I2C bus and streams snapshots over USB
    serial and BLE, with the DRV8833 motor outputs held inert. Includes
    the VL53L8CX library dependency and the breadboard wiring guide.
2026-06-01 feat: bring up 8x8 ToF + IMU streaming with self-diagnostics
    - Fix the VL53L8CX calls to the library's vl53l8cx_-prefixed methods
    and declare BLEInterface::sendStatus so the firmware builds.
    - Switch the ToF to 8x8 (64 zones) and emit snapshots at 10 Hz for
    usable host-side gyro integration.
    - Drop the I2C clock to 100 kHz for the SATEL's flying-lead wiring.
    - Surface ToF init failures in the stream: per-step status codes plus
    a live 0x29 bus probe in the offline line, since the native USB-CDC
    port can't be RTS-reset to read boot logs.
    - Enlarge the snapshot buffer to fit the 8x8 grid.
    [main.cpp]
2026-06-01 feat: add sensor listener and IMU-fused point cloud tools
    - sensor_listen.py: stream the sensor snapshots over serial or BLE.
    - pointcloud.py: live 3D point cloud from the 8x8 ToF grid, with
    complementary-filter orientation from the IMU (accel-anchored
    roll/pitch, gyro-integrated yaw) and voxel-grid accumulation over
    time. Rotation-only fusion; assumes the ToF and IMU are rigidly
    co-mounted (configurable via --mount-deg).
    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
2026-06-01 docs: correct SATEL-VL53L8 power wiring
    The board's onboard LDOs run from 5 V on 5VO (gated by PWREN, a logic
    enable); the 1V8/3V3/IOVDD pins are regulator outputs, not inputs.
    Fix the wiring table to power from 5 V, add the SPI_I2C_N and NCS
    mode-select pins, and document the "0x29 NACK -> SATEL unpowered"
    troubleshooting path now surfaced by the firmware.
2026-06-01 chore: esp32 boot documentation
2026-06-01 feat: gate sensor bench behind ENABLE_SENSOR_MODE flag
    Restore car control (motor + steering servo from serial/BLE drive
    commands) as the default build, and move the MPU/ToF sensor streaming
    behind ENABLE_SENSOR_MODE in config.h, disabled by default.
    Split the two modes into their own translation units guarded by the
    flag so only one compiles:
    - car_control.cpp (ENABLE_SENSOR_MODE == 0, default)
    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
2026-06-01 docs: document sensor mode and the point cloud tools
    Add docs/sensor-mode-and-point-cloud.md covering the ENABLE_SENSOR_MODE
    build, the snapshot stream format, and the sensor_listen.py /
    pointcloud.py tools (IMU-fused, time-accumulated 3D point cloud) with
    their controls, flags, and the rotation-only / mounting calibration
    caveats.
    Link it from the docs index and the tools README, and update
    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
2026-06-13 docs: add build photos to hardware and 3d-printing docs
    Replace the placeholder image references with real prototype photos:
    - README hero, motor placement, and adapters
    - motor-integration drive and steering sections (parts + installed)
    - ga12-n20 and sg90 3d-printing part photos
    - perfboard motherboard mounted on the chassis
2026-06-13 docs: update 3d-printing parts and add sg90 bracket
    - swap the N20 coupler and SG90 adapter STLs for the latest revisions
    - add the SG90 servo bracket part and document it with photos
    - refresh the STL filename references and the 3d-printing index
    [N20 - 2.5mm d hole - 2l.stl, N20 - 4.4mm.stl, S90 - 4.8mm - 6.5mm - 3l axle.stl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]
